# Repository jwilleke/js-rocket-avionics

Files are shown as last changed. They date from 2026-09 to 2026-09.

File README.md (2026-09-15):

# js-rocket-avionics

Carrier PCB and flight firmware for the [js-rocket](https://github.com/jwilleke/js-rocket) electronics sled.

__This is one candidate payload for the rocket, not *the* payload.__ The rocket flies on ballast alone. The interface it has to satisfy — 40.0 mm bore × 150 mm, an M3 × 55 retainer at nose z 15, a ~50 g mass ceiling, an optional camera port — is [`js-rocket/docs/payload-bay.md`](https://github.com/jwilleke/js-rocket/blob/main/docs/payload-bay.md), and that is the only page in that repo this project depends on.

__Flying the rocket, not building it? Read [docs/using-avionics.md](docs/using-avionics.md)__ — what the electronics do, and what to do before, during and after a flight. Everything below is for builders.

Separate from the rocket repo on purpose: `js-rocket` is geometry and documentation with no code, no package manager and no dependencies, and its `CLAUDE.md` says so explicitly. Copper, firmware and __the design record — every decision and why, in [docs/design.md](docs/design.md)__ — live here instead.

__Why it is built this way is in [docs/design.md](docs/design.md).__ __Every part this project needs is in [docs/BOM.md](docs/BOM.md), which is the single source of truth for part numbers and weights__ — plus what each part is, which board it serves, and what was rejected. __What was actually bought is in [docs/shopping-list.md](docs/shopping-list.md)__ — orders, costs, arrival status. The printed sled that carries these boards, and the [PayloadAdapter](https://github.com/jwilleke/js-rocket/blob/main/docs/3d-printed-parts/payload-adapter.md) it loads through, are rocket parts and stay in [js-rocket](https://github.com/jwilleke/js-rocket).

__Status: one two-sided board ([PCB-carrier-design.md](hardware/PCB-carrier/PCB-carrier-design.md)). Every footprint placed and netted, DRC 0 violations.__ The 10 unconnected items DRC reports are the signal nets, which are not routed yet (stage 2d, [#15](https://github.com/jwilleke/js-rocket-avionics/issues/15)). What the board is, both sides with a drawing, is [hardware/PCB-carrier/PCB-carrier.md](hardware/PCB-carrier/PCB-carrier.md).

> __Do not order it.__ It quotes cleanly, which is a toolchain check and nothing more. It is unrouted, and two checks are still owed (PCB-carrier-design.md, *Checks owed before building*).

## What a flight records

__Planned, not yet written.__ The recorder firmware on XIAO-ESP32S3-cam is __not started__ — today a flight would record nothing. The GPS is not recorded at all; its only copy is what the ground receiver hears.

| Data | From | Recorded? | Where it ends up |
|---|---|---|---|
| Acceleration and rotation | [LSM6DSO32](hardware/LSM6DSO32/LSM6DSO32.md), XIAO-ESP32S3-cam | __planned__ — 500 Hz, read from the sensor's FIFO | PSRAM through the flight (~900 KB a minute), __written to microSD in slices as it goes__ |
| Pressure, so altitude | [BMP388](hardware/BMP388-barometer/BMP388-barometer.md), XIAO-ESP32S3-cam | __planned__ — in the same log | the same |
| Video | OV3660 on the [Sense camera board](hardware/Sense-camera-board/Sense-camera-board.md), XIAO-ESP32S3-cam | __planned__ — from launch, with a few seconds before it, until landing is detected; idle on the pad | microSD, as it records |
| Position and GPS altitude | [L76K-GNSS](hardware/L76K-GNSS/L76K-GNSS.md), XIAO-ESP32S3-lora | __no__ — broadcast over LoRa by stock Meshtastic every so often, stored nowhere on the rocket | the ground receiver and the phone on it — [#23](https://github.com/jwilleke/js-rocket-avionics/issues/23), ordered 2026-09-11 |

__Two things that follow:__

- __A reset of XIAO-ESP32S3-cam in flight loses the slice of the sensor log not yet on the card__ — the rest is already written. Whether the shared battery browns it out is [#8](https://github.com/jwilleke/js-rocket-avionics/issues/8)
- __The sensor log has no GPS in it.__ The two XIAOs share power and nothing else, so position and motion are never in one record

Why the log sits in PSRAM rather than going straight to the card: [design.md](docs/design.md#data-path--why-the-log-lives-in-psram).

## The interface to the sled

__One board on the PayloadSled's centre line__, hanging off the web on two standoffs: the tall side (both XIAO stacks) faces 270°, the camera port; the low side (sensors, standoffs) faces 90°, the web. The sled side is [js-rocket#99](https://github.com/jwilleke/js-rocket/issues/99), which moves the web toward 90° and drills it at the standoffs. __Change these and the sled changes.__

| | Value |
|---|---|
| Board | __24.0 × 115.7 mm__, aft end at nose z 25.4, forward end 141.1 |
| Thickness | __1.6 mm__, 4 copper layers — OSH Park's only 4-layer thickness |
| Corner radius | 2.0 mm |
| Standoffs | __2 × Würth WA-SMSI M3, 10 mm__ (9774100360), low side, at board (x, y) __(12.0, 4.0)__ and __(16.5, 110.5)__ — nose z 29.4 and 135.9, neither under a module. M3 plastic screws, __M3 × 10__, from the web's far face |
| XIAO-ESP32S3-cam centre | board y __18.0__ (nose z 43.4), under the camera pad |
| XIAO-ESP32S3-lora centre | board y __68.0__ (nose z 93.4) |

Board x runs across the board, y from the aft end, forward positive, in KiCad's top view (the tall side). Everything above is read out of the generated board by `gen_carrier.py`; the gerbers in `fab/` predate it ([#16](https://github.com/jwilleke/js-rocket-avionics/issues/16)).

__Why 24 mm wide.__ It matches the web. The sensors, 17.8 mm across when lengthwise, sit inside it.

__Why 115.7 mm long.__ The camera fixes the cam XIAO at the aft end, and the tall side then carries the L76K-GNSS, the lora XIAO and the JST end to end. The low side carries the battery as well as the sensors (layout B2, 2026-09-15): LSM6DSO32 aft, the battery behind the L76K and the lora XIAO, the BMP388 forward of it — and the BMP388's M2 legs have to land between the tall side's header rows, which is what fixes where it can go. 90.4 mm until the battery moved onto the board.

__Why 1.6 mm.__ It is the only thickness OSH Park makes a 4-layer board in — "63mil (1.6mm) nominal". The 1.0 mm this page carried until 2026-09-15 was never checked against the fab; the operator caught it on the printed fit mock ("looks too thin"). It is also the better board: the standoffs are now __106.5 mm apart__ (81 before 2026-09-15), and 1.6 mm is __about 4× as stiff__ as 1.0 over that span (stiffness goes as thickness cubed). The low face — the standoffs' face — stays at r 0.5, so the sled does not change; the tall side moves __0.6 mm toward 270°__. What that costs across the bore is in [PCB-carrier-design.md](hardware/PCB-carrier/PCB-carrier-design.md#across-the-bore)

## The XIAO stack

__The expansion board — Sense or Wio-SX1262 — sits above the XIAO__, on the B2B connector on its front face. The XIAO stands on __two standard 7-pin headers__, ~2.50 mm, onto the board. No cutout and no tall stacking headers are needed. Stack heights and the fit across the bore are in [docs/design.md](docs/design.md#headers-and-the-expansion-board-on-top).

## Connections

There is __no schematic file__. Nets are assigned to pads directly in the generator, which is more robust than hand-authoring schematic s-expressions for 9 nets and keeps one generator as the single source of truth. The cost is no ERC and no drawn diagram — so this table *is* the wiring diagram. __Keep it in step with `gen_carrier.py`.__

| Net | From | Also reaches |
|---|---|---|
| `GND` | both XIAOs, pin 13 | In1 plane, every module, JST −, the `GND` wire pads |
| `+3V3` | XIAO-ESP32S3-cam pin 12 __only__ | In2 plane; LSM6DSO32 `VIN`; BMP388 `VIN` __and `CS`__ (I2C mode, [#19](https://github.com/jwilleke/js-rocket-avionics/issues/19)) |
| `+3V3_LORA` | XIAO-ESP32S3-lora pin 12 | the L76K-GNSS's `3V3` only — __kept off the plane__, so the two regulators are never paralleled |
| `SDA` | cam __D4__ (pin 5, GPIO5) | LSM6DSO32, BMP388 |
| `SCL` | cam __D5__ (pin 6, GPIO6) | LSM6DSO32, BMP388 |
| `BUZZER` | cam __D0__ (pin 1, GPIO1) | the buzzer wire pad; the PS1240 sits against the nose wall |
| `GPS_TX` | lora __D6__ (pin 7, GPIO43) | the L76K-GNSS's pad at the D6 position, which is the module's __RX__ |
| `GPS_RX` | lora __D7__ (pin 8, GPIO44) | the L76K-GNSS's pad at the D7 position, which is the module's __TX__ |
| `VBAT` | JST pin 1 | both XIAOs' BAT pigtail pads |

`GPS_TX` and `GPS_RX` are named from the XIAO's side. __Wire the L76K-GNSS by position, never by its silkscreen word__ — [L76K-GNSS.md](hardware/L76K-GNSS/L76K-GNSS.md#pinout--from-seeeds-schematic-not-the-listing).

### The pin map, and an error worth not repeating

The KiCad footprint numbers its pads 1–14 with no signal names, DIP-style — 1 at top-left, down to 7 at bottom-left, 8 at bottom-right, up to 14 at top-right. Seeed's pinout gives the meaning:

```text
pin  1  2  3  4  5  6  7   8  9  10  11   12   13   14
sig  D0 D1 D2 D3 D4 D5 D6  D7 D8 D9  D10  3V3  GND  5V
```

An earlier revision of the generator put GPS on pins 6/7 and I2C on 4/5 — which are __D5/D6 and D3/D4, every one off by one__. Caught by reading the mapping back out of the saved board rather than trusting the script's own output. The generator now names pins (`XIAO_PIN["D6"]`) so the numbers never appear by hand.

__Each 1×7 header numbers its own pads 1–7.__ The second row's pad 1 is XIAO pin 8, at the far end, so `xiao_pin = pad + 7` running back toward the USB-C. This file once said `15 − pad`, which is [#18](https://github.com/jwilleke/js-rocket-avionics/issues/18)'s mirrored row, written down as the rule.

## The GPS is an L76K

The MAX-M10S was rejected on 2026-08-06: __44.2 × 30.5 mm — wider than this 24 mm board — and ~$60__. The chosen part is Seeed's __L76K GNSS for XIAO (109100021)__ — 18 × 21 mm, UART on __D6/D7__. It takes its own footprint on the tall side, between the two XIAOs, and its antenna is a separate part on the sled. Pinout, power and orientation: [L76K-GNSS.md](hardware/L76K-GNSS/L76K-GNSS.md).

The same staleness once reached the barometer: __BMP390 → BMP388__, settled on 2026-08-06 when the 390 went out of stock. Same BMP3xx driver, same 25.5 × 17.8 mm STEMMA QT outline, address 0x77, and its pinout __confirmed off the physical part__.

## Battery — read before assembling

__BAT+/BAT− are underside pads on the XIAO__, not brought out to the castellated edge, so the battery cannot reach a XIAO through the headers. The battery lands on the JST at the board's forward end and reaches each XIAO by a short __soldered pigtail__.

- __Solder the pigtails before the XIAO goes onto its headers.__ The board, not the expansion board, is what covers the pads.
- __On battery power there is no voltage on the 5V pin__ — nothing can be fed from a XIAO's 5V rail.
- Both XIAO chargers sit in parallel on one battery. __Charge through one USB port at a time__, and read [why that is not sufficient on its own](hardware/LiPo-500mAh/LiPo-500mAh.md#two-chargers-on-one-battery).
- __Check JST pin 1 against the battery's red lead before soldering.__ The silkscreen marks `+`; reversing a LiPo into a XIAO destroys it.

## No RF on this board

The L76K and the Wio-SX1262 each carry their own U.FL connector, and both antennas mount on the sled, so __no RF ever crosses the carrier__. It is a purely digital and power board of 9 nets, which is what makes it tractable to generate and verify headlessly.

## Building

Requires KiCad 10. The generator uses KiCad's bundled Python so `pcbnew` matches the CLI exactly.

```bash
KPY=/Applications/KiCad/KiCad.app/Contents/Frameworks/Python.framework/Versions/3.9/bin/python3
CLI=/Applications/KiCad/KiCad.app/Contents/MacOS/kicad-cli

$KPY hardware/scripts/gen_carrier.py
$CLI pcb drc  --format json -o /tmp/drc.json hardware/PCB-carrier/PCB-carrier.kicad_pcb
$CLI pcb export gerbers -o fab/gerbers/ hardware/PCB-carrier/PCB-carrier.kicad_pcb
$CLI pcb export drill   -o fab/gerbers/ hardware/PCB-carrier/PCB-carrier.kicad_pcb
```

__The board is generated, not hand-edited.__ `.kicad_pcb` format shifts between KiCad releases; building it through `pcbnew` means the file is written by the same code that reads it. Edit `hardware/scripts/gen_carrier.py` and re-run — do not edit the board file directly, or the next run overwrites you.

`gen_outline.py` is the superseded 2a-only version, kept for reference.

DRC must report __0 violations__ before anything is ordered.

## Remaining stages

| Stage | State |
|---|---|
| 2a — outline, standoffs, stackup | __done__, one two-sided board |
| 2b — nets + footprints | __done__ — every footprint placed and netted |
| 2b — GND/+3V3 planes | __done__, In1 and In2 filled |
| 2c — placement | __done in the generator__, pending review of the drawing — [#14](https://github.com/jwilleke/js-rocket-avionics/issues/14) |
| 2d — signal routing | not started — [#15](https://github.com/jwilleke/js-rocket-avionics/issues/15) |
| 2e — Gerber + drill for fab | chain proven; needs a finished board |

__Do not order copper before breadboarding.__ A layout error costs ~$43 and two weeks; a wiring error costs minutes.

Fab target is __OSH Park__. The 24 × 70 mm version quoted **$26.00 for 3 copies** — OSH Park's 4-layer price is $10/in² for three — so 24 × 115.7 mm (4.30 in²) should land near __$43__. Re-upload to confirm; three copies — one to fly, two spares.

__OSH Park accepts the `.kicad_pcb` directly__ — confirmed by upload, not assumed. It read the layer count and outline unaided, so `fab/gerbers/` is not in the ordering path and exists only as a check that the export chain works.

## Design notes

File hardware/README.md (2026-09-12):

# Hardware

__One page per part, and the source of truth for the hardware in use.__ What each part is, its interfaces and dimensions, and the traps that are properties of the object.

__These pages are not a history and not a task list.__ They say what is, not what changed or what to do next. Decisions and open work live in [issues](https://github.com/jwilleke/js-rocket-avionics/issues); what happened in a session lives in `private/project_log.md`; the reasoning behind the design lives in [design.md](../docs/design.md).

__These pages also fix the vocabulary.__ A part is called by the name of its page here — [XIAO-ESP32S3-cam](XIAO-ESP32S3-cam/XIAO-ESP32S3-cam.md) and [XIAO-ESP32S3-lora](XIAO-ESP32S3-lora/XIAO-ESP32S3-lora.md), never "board A" and "board B" — and where a page has a plain-English word for the thing, that word is the one to use. __The [LiPo-500mAh](LiPo-500mAh/LiPo-500mAh.md) is the battery.__ It is not "the cell": that is a word from datasheets, it reads as jargon to everyone who has to work on this, and one battery made of one cell gains nothing by the distinction.

## The names, and where they live

__One folder per part. The folder, the page inside it and the part all carry the same name.__ Adopted 2026-09-09. `hardware/BMP388-barometer/BMP388-barometer.md` — not `README.md`, because a folder that already names the part does not need a second word for it. __A part's own photographs live in its folder__, beside its page.

__These are the names. Nothing else is a name for these things:__

| Folder and page | Is |
|---|---|
| `XIAO-ESP32S3-cam` | The MCU module carrying the camera. Never "board B", never "the Sense one" |
| `XIAO-ESP32S3-lora` | The MCU module carrying the radio. Never "board A" |
| `Sense-camera-board` | The expansion board on XIAO-ESP32S3-cam |
| `Wio-SX1262-LoRa` | The LoRa radio |
| `L76K-GNSS` | The GNSS module |
| `LSM6DSO32` | The IMU |
| `BMP388-barometer` | The barometer |
| `PS1240-buzzer` | The buzzer |
| `LiPo-500mAh` | __The battery.__ Never "the cell" |
| `Arming-switch` | The arming switch. __Not the JST__, which is a connector |
| `Stacking-headers` | The 7-pin strips |
| `Antennas` | Both U.FL antennas |
| `microSD` | The card |
| `PCB-carrier` | The carrier board |
| `camera-stack` | XIAO-ESP32S3-cam __with__ its Sense board — the assembly, not either part |
| `GNSS-stack` | __A rejected arrangement, not a thing that exists.__ Kept so it is not proposed again |

__Where a part has no folder here, it is not a part of this payload.__ "XIAO" on its own is not a name: there are two of them and they are not interchangeable.

__Two exceptions to "photographs live with the part".__ [`docs/resources/`](../docs/resources/) keeps the images that belong to __both__ XIAO modules — the front and back pinouts, the module and underside shots — because they document the model rather than either role, and a second copy is a copy that drifts. [`docs/bench-work/`](../docs/bench-work/) keeps what belongs to no part at all: the breadboard drawing, the bench photograph and the measurement grid.

__These pages hold no part numbers and no masses.__ [BOM.md](../docs/BOM.md) owns both and says so: *"anything else that quotes a part number or a mass is wrong — link here instead."* A number in two places is a number that will disagree with itself.

| | Page | Goes with | Photos | What it is |
|---|---|---|---|---|
| MCU | [XIAO-ESP32S3-lora.md](XIAO-ESP32S3-lora/XIAO-ESP32S3-lora.md) | — | grid | The MCU module. __Runs stock Meshtastic__ — identical to the cam copy to look at; [which is which](XIAO-ESP32S3-lora/XIAO-ESP32S3-lora.md#which-xiao-is-this-one) |
| MCU | [XIAO-ESP32S3-cam.md](XIAO-ESP32S3-cam/XIAO-ESP32S3-cam.md) | — | grid + bench | The MCU module. On the bench with both sensors and the buzzer; runs `bringup-cam` |
| Payload | [Sense-camera-board.md](Sense-camera-board/Sense-camera-board.md) | XIAO-ESP32S3-cam | grid ×2 | OV3660 camera and the microSD slot |
| Radio | [Wio-SX1262-LoRa.md](Wio-SX1262-LoRa/Wio-SX1262-LoRa.md) | XIAO-ESP32S3-lora | grid | LoRa. Buy as the matched kit, never separately |
| GNSS | [L76K-GNSS.md](L76K-GNSS/L76K-GNSS.md) | XIAO-ESP32S3-lora | grid | Position. __Flat on the carrier's tall side__, own footprint |
| Sensor | [LSM6DSO32.md](LSM6DSO32/LSM6DSO32.md) | carrier | grid + back | ±32 g IMU with a 9 KB FIFO |
| Sensor | [BMP388-barometer.md](BMP388-barometer/BMP388-barometer.md) | carrier | grid + 2 close | Unported barometer, 0x77 |
| Output | [PS1240-buzzer.md](PS1240-buzzer/PS1240-buzzer.md) | carrier | __none__ | Passive piezo. The only status channel on the pad |
| Power | [LiPo-500mAh.md](LiPo-500mAh/LiPo-500mAh.md) | carrier | __none__ | One battery, both XIAOs |
| Power | [Arming-switch.md](Arming-switch/Arming-switch.md) | battery lead | __n/a__ | In the battery line. __Flight 3 carries none__ |
| Storage | [microSD.md](microSD/microSD.md) | Sense camera board | __none__ | Video only |
| RF | [Antennas.md](Antennas/Antennas.md) | Wio-SX1262, L76K | grid | Both off-board on U.FL. ≥50 mm apart |
| Mechanical | [Stacking-headers.md](Stacking-headers/Stacking-headers.md) | both XIAOs | __none__ | 7-pin strips, ~2.50 mm standoff |
| Mechanical | [PCB-carrier.md](PCB-carrier/PCB-carrier.md) | everything | __n/a__ | The board, and the sled's structural span |
| Assembly | [camera-stack.md](camera-stack/camera-stack.md) | — | end + side | XIAO-ESP32S3-cam with its Sense board, as one object |
| Assembly | [GNSS-stack.md](GNSS-stack/GNSS-stack.md) | — | __none__ | __Rejected.__ Why the L76K is not in a stack |

## Photographs

__Each part's images live in that part's folder__, beside its page; the two shared XIAO images stay in [`docs/resources/`](../docs/resources/). Every one is embedded on the page above. __Shot on the printed measurement grid__ — part flat, square-on, calibration bar in frame. Method and its precision: [module-pinouts.md](../docs/module-pinouts.md#how-these-are-measured--photograph-on-the-grid-not-calipers).

| Image | Part | What it is for |
|---|---|---|
| [`BMP388-front-grid.jpg`](BMP388-barometer/BMP388-front-grid.jpg) | BMP388 | __Dimensional record.__ Header row along the bottom, mounting holes at the top corners |
| [`BMP388-front.jpg`](BMP388-barometer/BMP388-front.jpg) | BMP388 | Close-up. Confirms pin order on the silkscreen |
| [`BMP388-back.jpg`](BMP388-barometer/BMP388-back.jpg) | BMP388 | Close-up. Address jumper, `3 V` marking |
| [`LSM6DSO32-front.jpg`](LSM6DSO32/LSM6DSO32-front.jpg) | LSM6DSO32 | __Dimensional record.__ Both header rows and both mounting holes |
| [`LSM6DSO32-back.jpg`](LSM6DSO32/LSM6DSO32-back.jpg) | LSM6DSO32 | Close-up. `ST LSM6DSO32`, ±32 g, `0x6A` |
| [`L76K-GNSS.jpg`](L76K-GNSS/L76K-GNSS.jpg) | L76K | Module and its ≈25 mm patch antenna, to scale |
| [`Wio-SX1262-LoRa.jpg`](Wio-SX1262-LoRa/Wio-SX1262-LoRa.jpg) | Wio-SX1262 | FCC ID, U.FL, and the 2×5 header currently fitted |
| [`Wio-SX1262-LoRa-antennas.jpg`](Wio-SX1262-LoRa/Wio-SX1262-LoRa-antennas.jpg) | Antennas | Both Seeed strips, to scale |
| [`XIAO-ESP32S3-module.jpg`](../docs/resources/XIAO-ESP32S3-module.jpg) | XIAO ×2 | The MCU board. USB-C, U.FL, B2B, 14 pads |
| [`XIAO-ESP32-S3-bottom.jpg`](../docs/resources/XIAO-ESP32-S3-bottom.jpg) | XIAO ×2 | __The pin labels.__ Underside, where the silkscreen is — the only reading that confirms pad 1 is `D0`. See [module-pinouts.md](../docs/module-pinouts.md#xiao-esp32s3--read-off-the-underside-2026-09-08) |
| [`2026-09-12-XIAO-ESP32S3-cam-bench.jpg`](XIAO-ESP32S3-cam/2026-09-12-XIAO-ESP32S3-cam-bench.jpg) | XIAO-ESP32S3-cam | __Bench, not grid.__ The cam breadboard, sensors and buzzer wired, no Sense board — with the I2C wires on D3/D4, the slip since fixed |
| [`XIAO-ESP32S3-Sense-expansion.jpg`](Sense-camera-board/XIAO-ESP32S3-Sense-expansion.jpg) | Sense | Camera and microSD board |
| [`XIAO-ESP32S3-Sense-stack-end.jpg`](camera-stack/XIAO-ESP32S3-Sense-stack-end.jpg) | camera-stack | __End-on.__ Settled that the expansion board mates to the front face and sits above |
| [`XIAO-ESP32S3-Sense-stack-side.jpg`](camera-stack/XIAO-ESP32S3-Sense-stack-side.jpg) | camera-stack | The same assembly from the side |

## The two stacks

__Name everything by its page.__ There is no "board A", no "board B", and no functional nickname — the two MCU modules are told apart by which expansion board is on them, which is what their filenames say.

| | Mated to it | Firmware |
|---|---|---|
| __XIAO-ESP32S3-lora__ | [Wio-SX1262](Wio-SX1262-LoRa/Wio-SX1262-LoRa.md) radio, [L76K](L76K-GNSS/L76K-GNSS.md) GNSS | __none written__ — stock Meshtastic, pre-flashed |
| __XIAO-ESP32S3-cam__ | [Sense camera board](Sense-camera-board/Sense-camera-board.md) | custom, not started |

__The two XIAO modules are the same part but not interchangeable in practice__ — the lora one arrived with its 7-pin headers soldered on, the cam one did not.

Both ride the one [carrier PCB](PCB-carrier/PCB-carrier.md), on its tall side. The IMU and barometer sit on its low side, not on either expansion board; the buzzer and both antennas are off the board.

## Fasteners

__The carrier hangs off the sled's web on two surface-mount M3 standoffs__ (Würth WA-SMSI, 10 mm), with __M3 plastic screws, M3 × 10__, driven in from the web's far face (operator, 2026-09-11; [PCB-carrier.md](PCB-carrier/PCB-carrier.md)). The length matters: a longer screw passes through the standoff and out of the board's tall side. The old "M2 everywhere" standard (2026-09-05) was for screwing the breakouts down, which is no longer done.

__The sensors are not screwed through the board__, because nothing may stick out of its back: the LSM6DSO32 is soldered by both its rows, and the BMP388's free edge rests on __M2 bolts through its own holes, head down__ on the board. M2 survives only there, and only because those holes measure __Ø2.35__: an M2 passes, an M2.5 does not, and an M3 never could.

__Printed holes are modelled oversize.__ A hole modelled at nominal prints undersize by ~0.3 mm on the P2S, so the sled's M3 holes are drawn for clearance rather than at 3.0 — the same rule as the anchor bore in the rocket repo.

## What is not here

- __KiCad sources__ — [`PCB-carrier/`](PCB-carrier/), beside the page that documents the board
- __Generators__ — `scripts/`, including `gen_carrier.py`
- __Measured pin order and caliper readings__ — [module-pinouts.md](../docs/module-pinouts.md)
- __Why it is built this way__ — [design.md](../docs/design.md)
- __Bench drawings and the measurement grid__ — [`docs/bench-work/`](../docs/bench-work/)

---

Part numbers, vendors and masses live in [BOM.md](../docs/BOM.md), which is the single source of truth for both. Purchase history is in [shopping-list.md](../docs/shopping-list.md); the reasoning is in [design.md](../docs/design.md).

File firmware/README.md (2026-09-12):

# Firmware

__PlatformIO projects. No `.ino` files__ (operator, 2026-09-08).

A sketch carries its build configuration in IDE menu state — which board, whether PSRAM is on, which partition table. None of that is in the file, so a sketch that works on one machine fails on the next and the failure looks like a hardware fault. A `platformio.ini` puts every one of those settings in the repo, next to the code, under version control.

| Project | For | State |
|---|---|---|
| [`bringup-cam/`](bringup-cam/) | [XIAO-ESP32S3-cam](../hardware/XIAO-ESP32S3-cam/XIAO-ESP32S3-cam.md) + [Sense-camera-board](../hardware/Sense-camera-board/Sense-camera-board.md) bench bring-up, [#7](https://github.com/jwilleke/js-rocket-avionics/issues/7) | __run 2026-09-12, all pass__: I2C, IMU, a camera frame, 5 s of video, and a 1 MB PSRAM log flushed and read back. SD over SPI at 20 MHz, CS on GPIO21. Prints its device name, `mj-cam` |
| [`stack-load-test/`](../hardware/camera-stack/stack-load-test/) — __lives with [camera-stack](../hardware/camera-stack/camera-stack.md)__ | the camera stack at flight load: IMU + baro sampled into PSRAM while video records, all at once — design.md Verification item 4 | __run 2026-09-12__: zero dropped IMU samples in 60 s; 4.8% of frames dropped on purpose; worst card stall 1 191 ms |
| [`i2c-find/`](i2c-find/) | when `bringup-cam` finds nothing on the bus: which XIAO pins carry the I2C pull-ups, and on which pair the sensors answer | __run 2026-09-12__ — found the wires on D3/D4 |
| [`soak-power/`](soak-power/) | the shared-battery load test, [#8](https://github.com/jwilleke/js-rocket-avionics/issues/8) — drives capture + SD write bursts and logs every cycle and every reset to the card | __run 2026-09-12__: 67 minutes on the shared battery, 82 925 cycles, no reset on either board. Keeps a reset history in NVS as well as on the card |
| [`gps-check/`](gps-check/) | the [L76K-GNSS](../hardware/L76K-GNSS/L76K-GNSS.md) read directly, no Meshtastic, [#6](https://github.com/jwilleke/js-rocket-avionics/issues/6) — fix, satellites in view, best SNR, time to first fix. __Flashed onto XIAO-ESP32S3-cam__, so a GPS with no position in Meshtastic can be split into "module or antenna" against "Meshtastic not reading D6/D7" | __untested — no hardware has run it__ |

__Unplug XIAO-ESP32S3-lora before any upload.__ PlatformIO uploads to the first port it finds, and with both boards on USB that can be the one that must only ever carry stock Meshtastic.

```sh
cd firmware/bringup-cam
pio run -t upload && pio device monitor
```

__`soak-power` is flashed the same way and then run with the USB unplugged__, because USB-C powers the board and a monitored run measures the bench supply rather than the battery. Its record is `/soak-power.csv` on the card, read after the run.

__None of this is flight firmware.__ Bring-up proves the parts are alive and talking. Apogee, staging and landing detection need the flight profile settled first — see [design.md](../docs/design.md).

__[XIAO-ESP32S3-lora](../hardware/XIAO-ESP32S3-lora/XIAO-ESP32S3-lora.md) has no project here and must not get one.__ It runs stock Meshtastic, pre-flashed, and that is the entire reason there are two modules: a recovery beacon that cannot be broken by our own bugs. Writing firmware for it would throw that away. Updating it to a newer __stock__ release is allowed, on purpose and by a set procedure: [the firmware rule](../hardware/XIAO-ESP32S3-lora/XIAO-ESP32S3-lora.md#firmware--stock-meshtastic-only-updated-on-purpose-frozen-for-flight).

__Board settings come from the board definition, not from this repo__, and both projects pin `platform = espressif32@55.3.35` so that stays true across machines. What is a default, what is deliberately restated, and how to recover a board that will not take an upload: [sense-board-PlatformIO.md](sense-board-PlatformIO.md).

Procedure for running any of this: [bench-bringup.md](../docs/bench-bringup.md).

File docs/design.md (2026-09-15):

# Design record

__Why this payload is built the way it is.__ The decisions and the reasoning behind them, so the *why* survives into the work.

This project is __one candidate payload__ for the js-rocket [payload bay](https://github.com/jwilleke/js-rocket/blob/main/docs/payload-bay.md). The bay's interface — 40.0 mm bore × 150 mm, an M3 × 55 retainer at nose z 15, a ~50 g mass ceiling, an optional 8 mm camera port — is the rocket's business and is not restated here beyond what constrains the design.

Related: [BOM.md](BOM.md) (parts and masses) · [shopping-list.md](shopping-list.md) (what was bought) · [module-pinouts.md](module-pinouts.md) (footprint inputs) · [README.md](../README.md) (the carrier's frozen interface)

## Decisions locked

| Decision | Value | Why |
|---|---|---|
| MCU | __Two__ XIAO ESP32S3, told apart by the expansion board on each — __XIAO-ESP32S3-lora__ and __XIAO-ESP32S3-cam__ | Restores a zero-firmware recovery beacon and isolates it from flight-firmware failure |
| Interconnect | __One two-sided carrier PCB__ on the sled's centre line, hanging off an offset web on two M3 standoffs, 1.6 mm FR4, 4-layer, __24 × 115.7 mm__, the battery on its low face | Both XIAO stacks on one side, facing the camera; the web moved out of the board's way; removable as one unit |
| XIAO-ESP32S3-lora firmware | __Stock Meshtastic__, pre-flashed by Seeed. No code written | The Wio-SX1262 + XIAO ESP32S3 kit is a supported Meshtastic device out of the box |
| XIAO-ESP32S3-cam firmware | Custom — camera, sensors, PSRAM logging, Wi-Fi | Not yet started |
| Camera | __OV3660__ on the Sense expansion board — __confirmed off the ribbon 2026-09-06__, having been recorded as an OV2640 throughout | Estes AstroCam was considered and dropped |
| Barometric static port | __Dropped__ | See below |
| Apogee method | __Inertial primary__; GPS anchor by __offline timestamp merge__, not real time | The cost of putting GPS on the stock-Meshtastic board |
| Flight log storage | __Buffer in PSRAM, and write it to the card in slices as it goes__ (operator, 2026-09-12) | The sampler never writes the card itself — a separate writer task does, so a card stall delays the slice, never a sample |
| Power | __One battery__ to a carrier JST, distributed to each XIAO's __underside BAT pads by soldered pigtail__. __Charge through one USB port at a time__ | BAT is not on the castellated edge, so it cannot come through the headers. Avoids adding a charge IC |
| Arming | __In the battery line__, not on a GPIO — and __flight 3 flies without one__ (2026-09-08). Mechanism and status: [Arming-switch.md](../hardware/Arming-switch/Arming-switch.md) | Physically cuts power; zero pins; cuts both modules at once. Deferred rather than replaced: __nothing else takes the role__ |
| Antennas | __Both off-board on U.FL__ — GPS patch forward-facing, LoRa 82 mm whip up the ogive | A GPS patch needs a 30–40 mm ground plane; a 24 mm board never will be |

## Why two boards, after settling on one

A single board collapsed everything into one custom firmware image: DVP camera, microSD, PSRAM buffer, I2C sensors, SX1262 on non-standard pins, Wi-Fi, OTA. __No stock image does any of that__, which meant:

- first flight gated on firmware being *finished*, not merely working — the beacon __is__ the recovery system;
- a boot-loop at the pad requires removing the M3 × 55, the nose and the sled, with a laptop present, because USB is unreachable assembled and OTA needs firmware that boots;
- stock Meshtastic could not be flashed as a rescue, because the radio would be on custom pins.

Two boards restore the fallback and, as a side effect, dissolve two other problems: XIAO-ESP32S3-cam sheds LoRa (4 pads) and GPS UART (2), so __an I2C GPIO expander is no longer needed__, and XIAO-ESP32S3-cam's SPI carries only the microSD, so __a "no transmit while recording" scheduling rule is unnecessary__ — different MCU, different bus.

Two boards cost __~3 g__ against a single-MCU design, and buy the zero-firmware beacon, failure isolation, the end of pin scarcity, and the end of SPI contention.

## Why the barometric port is dropped

1. __No legal location.__ Ports need a straight section ≥1 caliber clear of any transition. Caliber is 56.7 mm; the longest straight run above the sled is the 56.7 body at __18.6 mm = 0.33 cal__.
2. __Cannot be built.__ Extending that body to a full caliber costs __+38 mm__ against __15.9 mm__ of P2S build headroom — the ogive would shorten and 3:1 fineness breaks.
3. __Unrepeatable.__ Hand-drilled into a part with no generator that takes 2 h 48 m to print.
4. __Drags a pressure bulkhead in with it__ — a new part and a new failure mode.
5. __Decisive: nothing consumes the number.__ No pyro channels; ejection is the motor delay. Apogee is data, not deployment.

A __barometer is still carried, unported and demoted__ to ejection-event timestamp and landing detection. A __contamination bulkhead__ (foam/plate, no sealing duty) still belongs at the sled base to keep black-powder particulate off the boards.

Side benefit: this frees the contested nose wall for the camera lens.

## The carrier PCB

__One two-sided board on the PayloadSled's centre line__, hanging off the web on two M3 standoffs (operator, 2026-09-11). The __tall side__ faces 270°, the camera port, and carries both XIAO stacks, the L76K-GNSS and the JST; the __low side__ faces 90°, the web, and carries the sensors. What the board is, both sides, is [PCB-carrier.md](../hardware/PCB-carrier/PCB-carrier.md); the design record is [PCB-carrier-design.md](../hardware/PCB-carrier/PCB-carrier-design.md). This section is why.

### How it got here

1. __Twin boards first__, one per XIAO. Dropped because each XIAO was thought to need a __cutout__ for an expansion board hanging underneath.
2. __One two-sided board on the sled's centre plane__ replaced it: 24 × 95 mm, lora on one face, cam on the other.
3. __Both premises failed.__ The expansion board sits __above__ the XIAO, so no cutout was ever needed. And the sled's web is a __solid 3 mm plate on that same centre plane__: the camera-port drawing every carrier dimension came from had modelled the board and the web in the same place ([#13](https://github.com/jwilleke/js-rocket-avionics/issues/13)).
4. __One board, the web moved.__ The operator kept one board: the web is offset toward 90°, out of its way, and the board hangs off it on standoffs, removable as a unit. Both tall stacks go on one side, one at each end.

### Headers, and the expansion board on top

__The expansion board — Sense or Wio-SX1262 — mates to the XIAO's __front face__, on the B2B connector beside the U.FL socket, and sits __above__ the XIAO.__ The XIAO sits on __two 7-pin headers__, one down each long edge, onto the carrier.

__An old Population table put the expansion board beneath the XIAO, and it was wrong.__ Settled 2026-09-08 against Seeed's front and back pinouts and an end-on photograph of the assembled stack — breadboard, header pins, XIAO, B2B block, expansion board, camera. See [XIAO-ESP32S3-cam.md](../hardware/XIAO-ESP32S3-cam/XIAO-ESP32S3-cam.md#which-face-carries-what--settled-off-seeeds-two-drawings-and-the-stack-itself).

__The back face stays open__, carrying `BAT+`/`BAT−`. The expansion board never covers them; the __carrier__ does, at 2.50 mm, which is why the pigtail is soldered before the XIAO goes onto its headers.

__Measured on the assembled stacks__ — heights from the bottom of the XIAO's PCB, camera excluded, with the headers' 2.50 mm added: __XIAO-ESP32S3-cam 10.72 mm, XIAO-ESP32S3-lora 11.82 mm__.

__How they fit across the 40 mm bore__, with the board on the centre line and the web offset toward 90°:

```text
tall side, toward 270   cam stack top r 11.8   camera pad floor r 14.09   2.3 mm for the ribbon
                        lora stack top r 12.9   its corners r 15.67        4.3 mm inside the door
low side,  toward 90    sensors top r 8.8       web r 10.5-13.5            1.7 mm clear
```

> __An earlier revision of this section had the expansion board hanging __below__ the XIAO in a ~14 mm header gap, giving a 15 mm stack.__ That is not how the parts assemble. The kit's standard 7-pin headers — ~2.50 mm standoff — are adequate, and no tall stacking headers are needed.

The camera hangs off the expansion board __on a flexible ribbon__, so its position is not fixed by the stack.

### Population — one board, two sides

| Side | Faces | Carries |
|---|---|---|
| __Tall__ | 270°, the camera port | XIAO-ESP32S3-cam + Sense camera board (aft, under the camera); L76K-GNSS; XIAO-ESP32S3-lora + Wio-SX1262 (forward); the battery JST |
| __Low__ | 90°, the web | LSM6DSO32 and BMP388, lengthwise; two M3 standoffs |

__The buzzer and both antennas are not on the board.__ The PS1240 sits against the nose wall on two wire pads; the antennas are on the sled ([Antennas.md](../hardware/Antennas/Antennas.md)). Net list: __9 nets__ — +3V3, +3V3_LORA, GND, VBAT, SDA, SCL, BUZZER, GPS_TX, GPS_RX. The wiring table is in the [README](../README.md).

### The GPS is an L76K, not a MAX-M10S

The MAX-M10S was rejected on 2026-08-06: **44.2 × 30.5 mm, wider than the 24 mm carrier, and ~$60**. Seeed's **L76K GNSS for XIAO (109100021)** is 18 × 21 mm, $11.99, active antenna included, and talks UART on __D6/D7__ — already the carrier's netlist.

__It plugs onto the XIAO's own 14 pads rather than presenting a header to the carrier__, so it takes the carrier as a footprint of its own, __on the tall side between the two XIAOs__ (operator, 2026-09-09; 2026-09-11). __Flat on the carrier deleted the stack-height risk__ rather than answering it: whether the L76K cleared the Wio-SX1262 on the B2B was never tested, and a four-high column cantilevered off header pins under boost was the alternative. Component side up it shows a XIAO's __back__ pattern, so its footprint takes the mirrored mapping — see [L76K-GNSS.md](../hardware/L76K-GNSS/L76K-GNSS.md#pinout--from-seeeds-schematic-not-the-listing).

### Power, and the pigtail constraint

__BAT+/BAT− are underside pads on the XIAO__ (footprint pads 16/17, 2.3 × 1.3 mm at x = −4.5), not brought out to the castellated edge — so the battery __cannot__ reach a XIAO through the headers.

- The battery lands on a __JST-PH at the board's forward end__; short __soldered pigtails__ run to each XIAO's BAT pads.
- __Solder those pigtails before the XIAO goes onto its headers.__ The carrier, not the expansion board, is what covers the pads.
- __On battery power there is no voltage on the 5V pin__, so nothing can be fed from a XIAO's 5V rail.
- Both XIAO chargers sit in parallel on one battery. __Charge through one USB port at a time__ — and [one port at a time is not sufficient on its own](../hardware/LiPo-500mAh/LiPo-500mAh.md#two-chargers-on-one-battery).

### Arming

__Flight 3 carries no arming switch__ (operator, 2026-09-08) — see [Arming-switch.md](../hardware/Arming-switch/Arming-switch.md). The part is deferred, not replaced, and __nothing else is promoted into the role__: power is made and broken at the battery's JST, which is a connector and stays one.

__The architecture below is what this document owns, and it has survived every revision of the mechanism__ — it is what any later flight's switch has to satisfy. The switch sits __in series in the battery line__, between the battery and the carrier's JST. It physically cuts power rather than setting a firmware state a boot-loop could defeat, it costs __zero GPIO__, and it __cuts both modules at once__ — arming is all-or-nothing, including the beacon.

__Everything else about it belongs to [Arming-switch.md](../hardware/Arming-switch/Arming-switch.md)__ — which mechanism, what is still open, and why the reed switch, the magnet-polarity question and the MOSFET that used to live in this section are all gone. The short of it: this payload has no pyro, so an "armed" rocket here is one that is recording video, and the switch buys __turnaround, not safety__.

### Build rules

- __4-layer, solid ground plane.__ A few dollars more at this size; fixes return paths and coupling from the camera's DVP flex.
- __1.6 mm FR4__ — OSH Park's only 4-layer thickness ([why](../README.md#the-interface-to-the-sled)). The board hangs off the web on two standoffs 106.5 mm apart; the web is the structure.
- __Module footprints, not bare chips.__ A bare LSM6DSO32 is an LGA-14 at 2.5 × 3 mm and is not hand-solderable. Soldering breakouts down still gives one rigid assembly — apart from the battery pigtails and link, which are unavoidable.
- __Low side first.__ The sensors stand ~1 mm proud on their pins and are soldered before the tall side's modules — [PCB-carrier.md](../hardware/PCB-carrier/PCB-carrier.md#build-rules).
- __Shock.__ Solder the headers — no loose sockets. The battery is tie-wrapped to the sled, never hung off the JST. Conformal coat after bench testing.
- __Mark polarity__ at the JST and the `VBAT` pads — reversing a LiPo into a XIAO destroys it.

## Data path — why the log lives in PSRAM

__The camera is not on SPI.__ The OV3660 uses a __DVP parallel bus__ (14 GPIO) plus I2C/SCCB for control, with frames landing in PSRAM by DMA. What touches SPI is *writing those frames to the microSD*.

__SD latency is unbounded.__ Cards run wear-levelling and garbage collection at will; a normally-2 ms write can take __100–250 ms__, spec-legally — and __the card in hand stalled up to 1 191 ms__ on the bench, 2026-09-12 ([microSD.md](../hardware/microSD/microSD.md#on-the-bench)).

__Internal flash is worse.__ Writing ESP32 internal flash __disables the instruction cache__. A 4 KB sector erase takes ~20–40 ms, during which code executing *from* flash stalls, including ISRs not marked `IRAM_ATTR`. At 500 Hz the sample period is 2 ms, so one erase silently drops __10–20 samples__ — during boost, where the data matters most.

__So: the sampler writes only to PSRAM.__

```text
500 Hz x ~30 B x 60 s  =  900 KB
ESP32-S3R8 PSRAM       =  8 MB
```

The whole flight fits roughly nine times over.

__And the log goes to the card in slices as it is recorded__ (operator, 2026-09-12, [#24](https://github.com/jwilleke/js-rocket-avionics/issues/24)). The sampler never touches the card: a separate writer task, the one that writes the video, copies each new slice from PSRAM to the card, and the PSRAM copy stays whole until landing. A card stall delays a slice and costs no sample — measured: zero dropped at 833 Hz accel + gyro while the card stalled up to 1.2 s ([camera-stack.md](../hardware/camera-stack/camera-stack.md#at-flight-load--stack-load-test)). What slicing buys is a reset: it now costs only the slice not yet written, not the flight. This replaces "zero SD writes in flight, flush on landing", which assumed one thread doing everything.

__Video runs from launch until landing is detected__, then stops (operator, 2026-09-12 and 2026-09-13, [#24](https://github.com/jwilleke/js-rocket-avionics/issues/24)). One battery feeds the beacon too, and the camera and card are its largest load.

- __Idle on the pad, not recording__ (2026-09-13). Plugging the battery in is "on" and the pad wait can be long; at full load the battery lasts 103 minutes ([#8](https://github.com/jwilleke/js-rocket-avionics/issues/8)), and most of that went to recording a rocket sitting still. __Launch detection starts the card writes__
- __A few seconds kept from before launch__ — a ring of recent frames in PSRAM, flushed when launch is detected, so the ignition is on the video. That needs the camera running on the pad, which costs part of the saving; __the pad draw with and without it is to be measured__ (USB meter) before the firmware settles it. Camera off until launch saves more but loses the first ~½–1 s of boost while it starts
- __After landing, recording stops__, and what is left of the battery keeps the beacon talking

## Sensor rationale

- __17.6 g peak on a D12.__ 32.90 N peak thrust / 0.190 kg liftoff mass. __±16 g phone-grade IMUs clip during boost__, and a clipped boost integral destroys the velocity estimate for the whole flight. This is why TeleMega carries an ADXL375, and why __LSM6DSO32 (±32 g)__ was chosen. Cost: less resolution in coast.
- __The gyro is not the apogee sensor.__ The accelerometer is. The gyro exists so body-frame acceleration can be rotated into the earth frame and gravity subtracted off the correct axis as the rocket tips over.
- __Use the IMU's FIFO — do not poll at 500 Hz.__ The LSM6DSO32 carries a 9 KB FIFO. Batch-reading cuts ISR load, relieves the PSRAM path, and means a brief stall queues samples in the sensor instead of losing them. __Treat a FIFO as a hard requirement on any substitute.__
- __The buzzer does three jobs.__ (1) Last-20-metre locator — GPS lands you in a 3–10 m circle and a white PLA rocket vanishes in tall grass at 2 m. (2) __The only status channel on the pad__ — with the nose assembled, USB is unreachable, Wi-Fi is off, and the GPIO21 LED is sealed inside, so beep patterns are the only way the rocket reports booted / armed / sensors alive. (3) Beeping apogee in digits after landing, needing no phone.
- __The buzzer is *passive*, PWM-driven from D0.__ An earlier revision specified an active self-oscillating part, because the buzzer then hung off an I2C GPIO expander where a ~3 kHz tone meant 6000 bus transactions a second. Two boards freed the pins, the expander went, and a real GPIO can PWM a passive element directly — giving __multiple tones__ rather than one, which is what makes beep patterns readable as distinct codes.
- __The buzzer is not radio redundancy__ — it shares XIAO-ESP32S3-cam's MCU. Only a self-powered beeper with its own battery (~5 g, zero pins) is immune to firmware and MCU failure. Not adopted; revisit if recovery confidence matters more than grams.
- __Sound must escape a sealed PLA cone.__ A piezo in a closed cavity loses 20–30 dB. Mount the disc __against the nose wall__ so the shell acts as a soundboard; the camera port is a free acoustic leak, and the bay is open at its base.
- __The barometer is interchangeable.__ With the static port dropped it is not the altimeter. __BMP388__ shares the BMP3xx driver so it is a drop-in for the out-of-stock BMP390, and a generic BMP280 would serve.

### IMU substitutes — the ±16 g trap

Anything with a ±16 g full scale __clips__ against the 17.6 g boost peak. That rules out almost every cheap module on the market — __MPU6050, LSM6DS3, ICM-20948, ICM-42688-P, ADXL345 are all ±16 g and all unusable here__, however attractive the price.

| Part | Range | Gyro | Note |
|---|---|---|---|
| __LSM6DSO32__ | ±32 g | yes | The chosen part. Adafruit 4692, or a clone — same STEMMA QT layout as the BMP388 |
| __BMI088__ | __±24 g__ | yes | Bosch drone/robotics part, widely stocked, ~$12. 36% margin over 17.6 g |
| __MPU6050 + ADXL375__ | ±16 g + ±200 g | yes | Two chips: one for coast and attitude, one for boost |
| __MPU6050 + H3LIS331DL__ | ±16 g + ±400 g | yes | Same split, more headroom |

The two-chip split is where this design began, before it was consolidated to a single LSM6DSO32 to save a gram. __Reverting costs +1 g and one I2C address — no extra pins.__ A cheap fallback rather than a compromise.

__Integrated 10DOF modules were evaluated and rejected.__ The DFRobot Gravity 10DOF (BMI323 + BMM350 + BMP581, $19.90) is representative: its BMI323 maxes at ±16 g. It is also 32 × 27 mm — wider than the carrier — uses a PH2.0 flying lead, and carries a magnetometer this design deliberately excludes.

## The camera, and the port it needs

> __The part is an OV3660, not an OV2640__ (confirmed 2026-09-06). The analysis below was written for a 2640 and __survives almost intact__: the OV3660's active area is 2048 × 1536 at 1.75 µm = 3.584 × 2.688 mm, a __4.480 mm__ diagonal against the 2640's 4.482 — two microns apart, the same optical format. __What would move the cone is a different focal length__, which a 3 MP module may well carry: at f 4.0 the cone is 58.5°, at f 3.6 it is 63.8°, at f 3.0 it is 73.5°.
>
> __A wider cone makes the port harder.__ At 50° the full cone already needs Ø14.2 mm outside a 15.0 mm collar; at 70° it needs Ø21.3. It was unbuildable from a board-mounted lens and it gets worse. __The standoff fix holds across the whole range__ — with the lens at r 19 the port is Ø4.9 at 50° and Ø7.3 at 70° — which is why bringing the lens to the wall was the right answer rather than a bigger hole.
>
> __Measure the cone rather than looking the lens up.__ Photograph a ruler at a known distance and compute the captured angle. That settles it for the real lens, and this project has already had one argument with a datasheet over this exact number.

__The OV2640's real FOV is ~50°, not the 65–68° commonly quoted.__ Active area diagonal is √(3.590² + 2.684²) = __4.482 mm__; with the stock __f = 4.8 mm__ lens that gives `2·atan(4.482/9.6)` = __50.1° diagonal__ (HFOV 41°, VFOV 31°). The sensor's __25° chief ray angle__ independently confirms it — a 25° half-angle *is* a 50° full cone. The 65–68° figure is inconsistent with both and should be disregarded.

Vignetting is governed by `FOV_cleared = 2·atan(D / (2·(L+S)))`, where L is wall thickness and __S is lens standoff behind the inner wall face__. Standoff, not wall thickness alone, is the constraint:

| Hole D | Standoff budget @ 50° | @ 68° (pessimistic) |
|---|---|---|
| 6 mm | 2.23 mm | 0.25 mm |
| __8 mm__ | __4.38 mm__ | __1.73 mm__ |
| 10 mm | 6.52 mm | 3.21 mm |

__8 mm it is__, and the assembly constraint that follows: keep the lens front element __within ~4.4 mm of the bore's inner face__. Where that hole may be drilled, and the rules for drilling it, are the rocket's business — [payload-bay.md](https://github.com/jwilleke/js-rocket/blob/main/docs/payload-bay.md#the-camera-port).

- __Do not fit the wide-angle lens.__ The 120–160° M7 option cannot match the 25° CRA, producing severe corner vignetting and colour crosstalk, and it would need a far larger hole in a load-bearing collar.
- __Focus is adjustable__ via the M5/M6 lens thread. Hyperfocal at f/2.8 with a ~4.4 µm circle of confusion is ~1.9 m, so everything past ~1 m is sharp.
- __Do not extend the camera flex__ — the DVP bus runs a ~20 MHz XCLK. XIAO-ESP32S3-cam's position on the carrier is what puts the XIAO at nose z 30..45 instead.

## PCB staging

Fab-ready Gerbers are the *output* of a routed board, not something authored directly.

| Stage | Deliverable | State |
|---|---|---|
| 2a | Board outline, mounting holes, stackup | __done__, DRC clean |
| 2b | Nets and footprints | __partial__ — XIAOs placed and netted, pin mapping now asserted on every generate ([#18](https://github.com/jwilleke/js-rocket-avionics/issues/18), closed `c2468eb`); sensors, buzzer, JST deferred |
| 2c | Placement — module positions, keepouts, ≥50 mm antenna separation | blocked on confirming real module pinouts |
| 2d | Routing — 4-layer. Autorouting is wrong here; needs interactive KiCad | not started |
| 2e | Gerber RS-274X + Excellon drill export | chain proven; needs a finished board |

__The PCB outline and mounting-hole pattern had to be frozen before the sled generator was written__, since the sled's rail bosses derive from them.

__Do not order copper before breadboarding.__ A layout error costs ~$33 and two weeks; a wiring error costs minutes.

### Supplier: OSH Park

| Supplier | Fit for this board |
|---|---|
| __OSH Park__ | Quoted __$26.00 for 3 copies__ of the 24 × 70 mm 4-layer board, ENIG standard, __free US shipping__, no customs. Three copies is right: two populated plus a spare. __Recommended__ |
| JLCPCB | Cheaper per unit but __minimum 5__, and shipping (~$20) erases the saving at this size. Right choice if a PCBA service is ever wanted |
| PCBWay | More flexible quoting, generally above JLCPCB's economy tier for simple SMT |

OSH Park wins because we already chose __hand-soldered module footprints__, so assembly service — JLCPCB's real advantage — buys nothing. ENIG also suits the U.FL connectors better than HASL. Trade-off: ~2 week lead versus JLCPCB express.

__Confirmed by upload, not estimated.__ OSH Park accepted the generated `.kicad_pcb` __directly__, detecting 4 layers and the outline unaided — so the Gerber export is not in the ordering path at all. The 95 mm board is 3.53 in² and should land near __$33__; re-confirm at order time.

## Firmware

__Board A needs none__ — the Seeed kit arrives pre-flashed with Meshtastic, and that is the entire premise of the two-board split.

__Board B's flight firmware does not exist yet.__ Camera, sensors, PSRAM buffering, landing detection and the post-landing flush all live there, and nothing has been written.

## Flight sequencing

> __Superseded — operator, 2026-09-13: the avionics fly all or nothing.__ The first avionics flight, [js-rocket flight 3](https://github.com/jwilleke/js-rocket/issues/63), carries the beacon, the recorder and the camera together, or it flies on ballast alone. No beacon-only flight. The staging below is kept as the reasoning it replaced: its job — prove each part before trusting the next — was done on the bench instead ([#4](https://github.com/jwilleke/js-rocket-avionics/issues/4)): the beacon's GPS and Meshtastic ([#6](https://github.com/jwilleke/js-rocket-avionics/issues/6)), the recorder and video, and all of it together on one battery with zero dropped samples ([#7](https://github.com/jwilleke/js-rocket-avionics/issues/7), [#8](https://github.com/jwilleke/js-rocket-avionics/issues/8)). What the bench cannot prove — range from altitude, GPS through PLA in flight — rides on the one flight. So the recorder firmware ([#24](https://github.com/jwilleke/js-rocket-avionics/issues/24)) gates flight 3.

Do not fly all the variables at once.

```text
flight 1   XIAO-ESP32S3-lora only, stock Meshtastic, no camera
           validates: airframe, recovery, GPS lock through PLA, LoRa range from altitude
flight 2   + XIAO-ESP32S3-cam flight recorder (sensors, PSRAM log)
flight 3   + video
```

Each flight adds one thing, and the recovery beacon is proven before anything expensive rides on it. __This is only possible because XIAO-ESP32S3-lora needs no firmware.__

## Verification

1. __Bench prototype before layout.__ Breadboard both populations. Prove XIAO-ESP32S3-lora enumerates as a Meshtastic device untouched, and that XIAO-ESP32S3-cam boots with camera, SD and I2C sensors live, with the strapping pins (GPIO3, 43, 44) behaving.
2. __Confirm the silicon matches the label__ before designing footprints round it — see [module-pinouts.md](module-pinouts.md).
3. __PCB bring-up__ — power, then XIAO-ESP32S3-lora: GPS UART and LoRa; then XIAO-ESP32S3-cam: I2C enumeration and camera. __Measure GPS lock time with the LoRa transmitting__, since desense cannot be reasoned about from a schematic.
4. __Sample-rate integrity under load__ — run XIAO-ESP32S3-cam's 500 Hz sampler with the camera recording to SD and confirm __zero dropped samples__ by checking timestamp deltas, not by trusting the loop. __Done on the bench, 2026-09-12: zero dropped__ at 833 Hz accel + gyro for 60 s while recording, judged by the FIFO's own overrun flag — [camera-stack.md](../hardware/camera-stack/camera-stack.md#at-flight-load--stack-load-test). Repeat on the carrier and on the battery ([#8](https://github.com/jwilleke/js-rocket-avionics/issues/8)).
5. __Shared-battery behaviour__ — confirm the camera's inrush on XIAO-ESP32S3-cam does not brown out XIAO-ESP32S3-lora, and that charging through one USB port with both BAT pads connected behaves.
6. __Buzzer audibility, assembled__ — beep inside a closed Nosecone and listen from 20 m. A sealed cavity costs 20–30 dB; couple the disc harder to the shell before considering a dedicated sound hole.
7. __Mass__ — weigh the loaded sled and hand the real number to the rocket's stability re-run, [#9](https://github.com/jwilleke/js-rocket/issues/9). __Do not fly on the estimate.__

## Risks

- __One board carries both MCUs.__ A layout bug takes the beacon and the recorder together — the cost of a single carrier. Firmware and MCU failures are still isolated; only the copper is shared.
- __No real-time GPS anchor for the inertial log.__ GPS sits on the stock-Meshtastic board, which broadcasts position at a low rate and will not set the `airborne <4g` dynamic model, so lock may drop under boost. Altitude integration is anchored by an __offline timestamp merge__, which is weaker. Cross-linking a UART would fix it and would stop XIAO-ESP32S3-lora being stock, defeating the purpose.
- __A reset of XIAO-ESP32S3-cam loses the slice not yet on the card__ — no longer the whole flight, now the log is written in slices. Two bench findings make resets worth designing out: a task that never yields trips the watchdog, and a reset mid-write can leave the card unmountable until power-cycled ([camera-stack.md](../hardware/camera-stack/camera-stack.md#at-flight-load--stack-load-test)).
- __The PCB is on the critical path.__ Sled geometry derives from its outline and mounting holes, so a layout revision reprints the sled. Freeze the outline early; breadboard before committing to copper.
- __GPS desense from the LoRa transmitter__ cannot be reasoned away on paper. ≥50 mm antenna separation and both antennas on U.FL are the mitigations; verification step 3 is the proof.
- __Shared battery couples the boards__ — and on the bench it did not matter: 67 minutes at full camera load, down to ~3.5 V, reset neither board ([#8](https://github.com/jwilleke/js-rocket-avionics/issues/8), [LiPo-500mAh.md](../hardware/LiPo-500mAh/LiPo-500mAh.md#the-known-risk-observed-no-brownout-at-bench-load)). Repeat on the carrier. The coupling that does bite is charging: the beacon out-draws the charger, so the battery is charged off the carrier.
- __A welded arming contact leaves the camera running.__ It was recorded here as "an armed rocket that cannot be safed", which is a pyro rocket's hazard and not this one's — the correction and the live constraint are in [Arming-switch.md](../hardware/Arming-switch/Arming-switch.md).
- __Estimated masses were unreliable in both directions.__ Nine parts weighed 2026-08-17: the __L76K came in +184%__ and is now the heaviest object in the nose, while the Sense and the radio came in light. Net __+4.1 g__, putting the nose over its ~50 g target — see [BOM.md](BOM.md), which owns every weight.
- __The rocket's stability re-run ([#9](https://github.com/jwilleke/js-rocket/issues/9)) is P0 and blocking.__ This payload can be built and bench-tested now, but __it cannot be flown__ until that clears.

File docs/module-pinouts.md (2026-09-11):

# Module pinouts, measured off the parts

__Footprints cannot be drawn until these are read off the physical parts.__ Vendor listings copy Adafruit's product text verbatim, and this project has already caught two places where the board in hand disagreed with the datasheet it was sold under. A wrong pin order scraps a board rather than costing a re-solder.

__Both sensor boards are confirmed from the parts__ — the BMP388 by caliper, the LSM6DSO32 by pin order and markings off photographs and by every dimension a footprint needs ([#5](https://github.com/jwilleke/js-rocket-avionics/issues/5), closed 2026-09-06). __Nothing else is.__

Moved here from the rocket repo's `electronics-plan.md` — this is footprint input for the carrier PCB, so it belongs with the copper. What each part *is* and why it was chosen stays in [BOM.md](BOM.md); the design record stays in [electronics-plan.md](https://github.com/jwilleke/js-rocket/blob/main/docs/planing/electronics-plan.md).

## How these are measured — photograph on the grid, not calipers

__Adopted 2026-09-06, operator.__ These parts are 17–25 mm and their features sit on a 2.54 mm pitch; __reading 0.1 mm or better off them with calipers is not realistic__, and two attempts at it produced numbers that did not close (a header pair 0.49 mm over the board width, and hole spacing with two routes 0.16 mm apart).

__The method is: lay the part flat on the printed grid, shoot square-on from directly above, keep the calibration bar in frame, and read the dimensions off the image.__ The grid is [`pcb_measurement_grid.pdf`](bench-work/pcb_measurement_grid.pdf); the bar reads `CALIBRATION BAR 100.0 mm`, so the image's own scale is recoverable from the photograph regardless of camera distance.

Why it is better here:

- __It measures to the feature, not to whatever the jaws could reach.__ Most of the readings wanted are edge-to-hole-__centre__, which a caliper cannot do directly and a grid can
- __It is auditable.__ The photograph is committed, so a disputed number can be re-read years later without the part
- __It reads every dimension at once__, rather than one careful reading at a time
- __Its error is honest__ — perspective, and how squarely the shot was taken. Keep the camera above the part, not off to one side

__Realistic precision is ±0.2–0.3 mm__ on a square-on shot — __but only when the image is actually measured__, in an editor or a script that calibrates off the bar and reads pixel coordinates. It is worse than a caliper's theoretical resolution and __better than a caliper's actual result on parts this size__.

> __Eyeballing a photograph is not the same thing and does not get there.__ Reading these images by eye lands at roughly __±1 mm__, which is fine for confirming a pin count, a marking or a rough outline, and __not__ fine for a footprint. Two eyeball reads of the same LSM6DSO32 grid shot gave 24.3 and 24.7 mm against a board known to be 25.5. Where a number is going into copper, measure the image; do not squint at it.

## BMP388 — confirmed from the part

Eight pins, 0.1 in pitch, single row along one long edge, labels alternating above and below:

| Pin | 1 | 2 | 3 | 4 | 5 | 6 | 7 | 8 |
|---|---|---|---|---|---|---|---|---|
| | __VIN__ | 3Vo | __GND__ | __SCL__ | SDO | __SDA__ | CS | INT |

Identical to Adafruit 3966, which labels 4 and 6 as SCK/SDI for SPI — same pins. So it is a true layout clone and the STEMMA QT dimensions (25.5 × 17.8 mm, two mounting holes) hold.

__We use four: 1, 3, 4, 6__ — VIN, GND, SCL, SDA.

__The seller's wiring diagram is SPI, and following it will waste a bench session.__ It wires SCL/SDO/SDA/CS to Arduino 13/12/11/10, which are SCK/MISO/MOSI/SS — the hardware SPI pins. On BMP3xx the pins are dual-purpose: in SPI mode SCL is the clock, SDO is MISO and SDA is MOSI. We use I2C, which needs only the four above.

Two I2C gotchas, both worth knowing *before* bring-up:

- __CS must be HIGH to select I2C.__ CS low puts a BMP3xx into SPI mode. Adafruit's layout pulls it up so I2C is the default and this is a layout clone — but __if the sensor does not enumerate at 0x77, check CS first__. It is the most likely cause.
- __SDO selects the address, it is not data.__ High = 0x77 (default, jumper open), low = 0x76. Leave it alone unless a second barometer is ever added.

__Power to VIN, never to 3Vo.__ `3Vo` is the on-board regulator's *output*; back-feeding it kills the LDO.

__The `3-5VDC` figure did not survive the part arriving.__ This section previously stated the back silkscreen read `Vcc/Logic: 3-5VDC`, which is Adafruit's wording and is what the listing copies. The board in hand is __marked 3 V__. Since the design runs +3V3 into VIN, nothing in it changes — but __5 V is no longer a documented fallback__, and the back silkscreen should be read cleanly before anyone relies on one. It is a good illustration of the rule at the top of this page: the listing describes Adafruit's board, not necessarily this one.

Back silkscreen also confirms __`addr default 0x77`__ with a solder jumper for 0x76, and SPI/I2C selectable.

Header ships __loose and un-soldered__, confirmed on the part — which keeps the mounting orientation open.

## BMP388 — measured 2026-08-08

Calipers and scale, on the board in hand. Photos: [front](../hardware/BMP388-barometer/BMP388-front.jpg), [back](../hardware/BMP388-barometer/BMP388-back.jpg).

| | Measured | Was assumed | |
|---|---|---|---|
| Mass | __1.8 g__ — [BOM.md](BOM.md) owns this figure | 1.0 g (old estimate) | __+80%__ |
| Thickness over Qwiic connectors | __4.79 mm__ | 4.4 mm (Adafruit) | +0.4 |
| Mounting-hole diameter | __Ø2.35 mm__ | 2.5 mm (Adafruit) | __undersize__ |
| Mounting-hole spacing | __20.58 mm__ | — | now known |
| Qwiic cables supplied | 2 × __110 mm__ | "two included" | — |

The front photo confirms the recorded pin order on the physical silkscreen — __VIN, 3Vo, GND, SCL, SDO, SDA, CS, INT__, labels alternating above and below the row — with the two Qwiic connectors on the short edges and both mounting holes on the long edge opposite the header. The layout-clone assumption holds.

__The mounting screw is M2, not M2.5.__ Ø2.35 mm passes an M2 (2.0 mm major) with 0.35 mm of total clearance; an M2.5 does not fit at all. Adafruit's own breakouts use 2.5 mm holes, so anyone sizing this off the datasheet rather than the part will pick a screw that will not go in.

__The sled's bosses must be modelled oversize.__ Same rule as the anchor bore in the rocket repo's [sections.md](https://github.com/jwilleke/js-rocket/blob/main/docs/sections.md) — a hole modelled at nominal prints undersize by ~0.3 mm on that printer. Model for M2 clearance accordingly, and do not copy the 2.35 mm figure straight into CAD.

__20.58 mm of spacing on a 25.5 mm edge__ puts the holes __2.46 mm in from each end__, which is the standard STEMMA QT placement and consistent with the clone claim. __Outline measured 2026-09-06: 25.5 × 17.8 mm__, matching Adafruit's published figures — the one dimension of theirs that survived contact with the part.

## LSM6DSO32 — read off photographs 2026-09-05, not off calipers

Photos: [front](../hardware/LSM6DSO32/LSM6DSO32-front.jpg), [back](../hardware/LSM6DSO32/LSM6DSO32-back.jpg).

__It does not share the BMP388's form factor, which this page assumed it would.__ Two header rows rather than one, and both mounting holes on the same edge as one of them:

| | BMP388 | LSM6DSO32 |
|---|---|---|
| Header rows | __one__, 8 pins | __two__ — 9-pin `Primary I2C/SPI`, 5-pin `Aux. I2C/SPI` |
| Mounting holes | long edge __opposite__ the header | flanking the __Aux__ row, on that edge |

__The flat-mounting conclusion survives, without screws__ (operator, 2026-09-11). Both rows soldered, Primary on one edge and Aux on the other, give two-point restraint across the board, and the part is too light to need more.

__Primary row, 9 pins:__ `VIN 3Vo GND SCL SDA DO CS I1 I2`, labels alternating above and below.

__Aux row, 5 pins:__ `SCX SDX CS DO GND`. Confirm the ordering against the part; a photograph is not a reading.

__Aux row position — measured off the photograph 2026-09-11, not eyeballed.__ It now matters: the row is soldered for support, so its pins must land in real holes. Method: ImageMagick connected components on the full-resolution `LSM6DSO32-front.jpg`, thresholding the gold pad rings and taking all 14 ring centroids, then using __the pin pitch itself as the ruler__ (2.54 mm, exact), so the result does not depend on the camera's scale.

| | Pixels | Result |
|---|---|---|
| Primary-row pitch, pins 1→9 | 198.05 per pitch | 77.97 px/mm |
| Aux pads against Primary pins 3–7 | within 4 px in x | __centred over pins 3–7__ |
| Row gap, three matched pairs | 993.8 mean | __5.02 pitches = 12.75 mm__ |

__So the Aux row is five pitches, 12.70 mm, from the Primary row__ — the standard Adafruit 0.1 in layout, in line with the mounting holes. The Y-offset table below implies 12.11, which would be 4.77 pitches, ~50 px away from what the image shows, so one of its two readings is off by ~0.6 mm. The footprint is drawn on 12.70. Seating the part in a breadboard by both rows is a free cross-check.

Back silkscreen: __`ST LSM6DSO32`__, `6-DoF Accel+Gyro IMU`, __`Accel ±4/8/16/32 g`__, `Gyro ±125~2000 dps`, __`I2C Addr 0x6A`__ with an `AD0` jumper, `I2C VLogic/Vcc: 3-5VDC`, STEMMA QT both short edges, board revision __B__.

Three things that follow:

- __The silicon matches the label__ — the check at the foot of this page passes on this part
- __±32 g is confirmed on the board itself__, not on a listing
- __0x6A does not clash with the BMP388's 0x77__, now confirmed from the part rather than from a datasheet

__`3-5VDC` appears on this board's back and is presumably true here__, unlike the BMP388, where the identical wording came off Adafruit's copy and the part in hand was marked 3 V. The design runs +3V3 either way.

### Measured 2026-09-05

| | Reading | Confidence |
|---|---|---|
| Mounting-hole spacing | __20.58 mm__ | *"appears to be"* — provisional |
| Thickness over Qwiic connectors | __4.80 mm__ | *"about the same"* as the BMP388's 4.79 |
| Header pitch | __2.54 mm__ | confirmed on the BMP388 and the XIAO |
| Board outline | __25.5 × 17.8 mm__ | measured 2026-09-06, __same as the BMP388__ |

__The two sensor boards are the same outline, the same hole pattern and the same thickness.__ 25.5 × 17.8, holes at 20.58 mm centres __2.46 mm in from each end__, 4.79/4.80 thick. For the carrier that means __one footprint outline and one hole pattern, placed twice and rotated__ — not two footprints.

__Both sensors take the same mounting pattern.__ 20.58 mm centres on the LSM6DSO32 against 20.58 mm on the BMP388, and 4.80 mm thick against 4.79 — indistinguishable at this precision. __So the carrier needs one hole pattern, placed twice__: two M2 clearance holes at 20.58 mm centres.

__What differs is not the pattern but its orientation.__ The BMP388's holes sit on the edge opposite its single 8-pin row; the LSM6DSO32's sit on its __Aux__ edge with the Primary row opposite. Same drill pattern, different rotation on the board.

__X positions, derived from the outline and the 2.54 mm pitch — no further measuring:__

| | Span | Inset per end, if centred |
|---|---|---|
| Mounting holes, both boards | __20.58__ | __2.46 mm__ |
| LSM6DSO32 Primary row, 9 pins | 8 × 2.54 = __20.32__ | 2.59 mm |
| BMP388 row, 8 pins | 7 × 2.54 = __17.78__ | 3.86 mm |

> __The holes do not line up with the end pins, and it is close enough to assume they do.__ At 2.54 mm pitch the LSM6DSO32's 9-pin Primary row spans __8 × 2.54 = 20.32 mm__ against a hole spacing of __20.58__. The holes sit __0.13 mm outboard of the end pins on each side__ — a real offset, and one that will not be visible by eye. Do not snap the footprint's holes to the end pads.

__Hole diameter is not an open question.__ The fastener is __M2 across the project__ (operator, 2026-09-05) — M3 does not fit these breakouts and nothing 2.5 mm is being bought. Footprints are drawn for __M2 clearance__, not for whatever a given board's hole measures.

## The Y offsets — measured 2026-09-06, both boards the same

Read off the parts by the operator, *"as best as I can do on these parts"*:

| | Reading |
|---|---|
| Header row centreline → near long edge | __2.54 mm__ |
| Header row centreline → far long edge | 15.75 mm |
| Mounting-hole centreline → far long edge | __14.65 mm__ (so __3.15__ from the near edge) |
| Mounting hole → each short side | __2.54 mm__ |

__Both boards read the same__, which is consistent with everything else: same outline, same pattern, same thickness.

### One pair closes and one does not

__The mounting-hole readings close exactly.__ 14.65 + 3.15 = __17.80__, the measured width. Take those as good.

__The header pair does not.__ 2.54 + 15.75 = __18.29__ against a 17.80 width — __0.49 mm over__, so one of the two is not an edge-to-centre reading. __Use the 2.54__: it is the short, easy reading, it sits on the 0.1 in grid these boards are laid out to, and the far edge then derives as __15.26 mm__. The 15.75 is most likely taken to the far side of the hole rather than its centre.

### The hole spacing has two routes and they differ by 0.16 mm

- From the short-side inset: 25.50 − 2 × 2.54 = __20.42 mm__
- Measured across the holes directly: __20.58 mm__

__0.16 mm, and that matters more than it looks.__ An M2 in a Ø2.35 hole has __0.35 mm of total clearance__, so a 0.16 mm error in hole spacing consumes __46% of it__ before any fabrication or print tolerance is added. It will very likely still assemble; it is not comfortable.

__Worth one tie-break reading before the board is fabricated__, not before the footprint is drawn: outside-edge to outside-edge across both mounting holes, minus one hole diameter. Whichever number that supports becomes the footprint's. Until then the footprint is drawn on __20.58__, the direct measurement of the thing that actually matters.

__Nothing further is needed to draw the footprint.__ Outline, pitch, hole pattern and both Y offsets are in hand, and every X position falls out of the outline and the 2.54 mm pitch.

__This tie-break no longer gates fabrication__ (2026-09-11): nothing screws a sensor into the carrier any more. The holes only take the BMP388's M2 leg bolts, which rest on the board, so 0.16 mm does not matter.

## XIAO ESP32S3 — read off the underside 2026-09-08

__The pinout the whole carrier netlist rests on, and until now it was never verified.__ Read off [`XIAO-ESP32-S3-bottom.jpg`](resources/XIAO-ESP32-S3-bottom.jpg) — the labels are on the __underside__, which is why the earlier top-face photo could not settle it.

Underside view, USB-C at the top. __The columns are mirrored from the top view__, which is the trap:

```text
left  column, top -> bottom    5V   GND  3V3  D10  D9  D8  D7
right column, top -> bottom    D0   D1   D2   D3   D4  D5  D6
```

So the numbering runs __D0..D6 down one side, then D7, D8, D9, D10, 3V3, GND, 5V back up the other__:

| Pin | Label | | Pin | Label |
|---|---|---|---|---|
| 1 | __D0__ | ← USB end → | 14 | __5V__ |
| 2 | D1 | | 13 | __GND__ |
| 3 | D2 | | 12 | __3V3__ |
| 4 | D3 | | 11 | D10 |
| 5 | D4 | | 10 | D9 |
| 6 | D5 | | 9 | D8 |
| 7 | __D6__ | ← far end → | 8 | __D7__ |

__Three things this confirms, none of which had been checked:__

- __`RF_Module:MCU_Seeed_ESP32C3`'s geometry is correct for an ESP32-__S3__ board.__ `gen_carrier.py` takes its pad grid from a __C3__ footprint while the parts in hand are S3. The XIAO form factor is standard across variants — but that was an assumption, and this is the reading that supports it.
- __`XIAO_PIN` in `gen_carrier.py` matches the silkscreen__, so [#18](https://github.com/jwilleke/js-rocket-avionics/issues/18)'s fix lands the nets on the right physical pins, not merely on the right footprint pads.
- __Pin 1 = D0 sits at the USB-C end__, so the USB-C faces __aft__ on the carrier. [#1](https://github.com/jwilleke/js-rocket-avionics/issues/1)'s charging pigtail depends on that and had been resting on an inference.

__Also visible and consistent with [XIAO-ESP32S3-cam.md](../hardware/XIAO-ESP32S3-cam/XIAO-ESP32S3-cam.md):__ `BAT+`/`BAT−` are __centre pads on the underside__, not on the castellated edge — which is why the battery reaches each board by soldered pigtail rather than through the headers. The JTAG pads (`MTCK`, `MTDO`, `MTDI`, `MTMS`) sit between them.

## What is left

__Every part is in hand, and every part has an owner__ — a [hardware page](../hardware/README.md), which also indexes the grid photographs. Nothing here is waiting for a part to arrive.

- __Nothing is owed on the sensors.__ The LSM6DSO32's Aux row was measured off the photograph at 12.70 mm (above), and the hole-spacing tie-break no longer gates anything. The same measurement puts the holes at ~20.4–20.5 mm, leaning to 20.42
- __[L76K-GNSS](../hardware/L76K-GNSS/L76K-GNSS.md) has a pin order__, from Seeed's schematic (2026-09-10), __and the part is confirmed as V1.1__ off its own bottom silkscreen (operator, 2026-09-11), so Seeed's V1.1 drawing is the part in hand. The pads are the XIAO's pattern, and only D6, D7, 3V3 and GND are used; the table is on the part's page, which owns it — [#6](https://github.com/jwilleke/js-rocket-avionics/issues/6), [#14](https://github.com/jwilleke/js-rocket-avionics/issues/14)
- __[PS1240-buzzer](../hardware/PS1240-buzzer/PS1240-buzzer.md)__ — two pins. Nothing to read off it

__There is no reed switch__ — [Arming-switch.md](../hardware/Arming-switch/Arming-switch.md) owns what replaced it and why.

Purchase history is in [shopping-list.md](shopping-list.md).

## The mounting-orientation question

Both sensors put their header on __one edge only__. Two ways to mount, and it is a real 2c decision:

- __Perpendicular__ — header into the carrier, board standing up. Simple, but ~17.8 mm tall plus header against __19.7 mm__ available at the bore centre, and __cantilevered off the header alone__.
- __Flat__ — board parallel to the carrier, standing on its header pins, with the mounting holes doing the rest of the mechanical work. Lower and far better for shock.

__Flat is the answer, and the calipers settled it.__ On the BMP388 the two mounting holes sit at the corners of the edge *opposite* the header, with the Qwiic connectors on the short sides — confirmed on the part. Screws at one end and a soldered header at the other gives __two-point restraint__ across the board, exactly what boost loading wants and what perpendicular mounting cannot offer.

Flat also wins on height now that the board is measured. It stacks __4.79 mm__ plus standoff against the __19.7 mm__ available at the bore centre; perpendicular would stand 17.8 mm of board plus header into that same 19.7 mm, cantilevered off the header alone.

### The header is a straight kit-standard strip — settled 2026-09-08

__Straight headers. Not right-angle, not links.__ The board stands on its pins at the header's own __~2.50 mm__ standoff, parallel to the carrier, with __M2 spacers of the same height__ under the two mounting holes. Header edge and screw edge at the same height is what makes it flat.

__This design already does exactly that.__ A XIAO mounts flat on two straight 1×7 strips — see [Stacking-headers.md](../hardware/Stacking-headers/Stacking-headers.md) and [design.md](design.md). A sensor is the same problem with one header row instead of two, the screws standing in for the second row.

Right-angle would only be needed to lie a board flat with the header entering from the *side*, and nothing here asks for that. __An earlier revision of the bullet above offered "right-angle headers or short links" and never chose between them__; that clause appeared once, propagated to no part page, and was read as an open decision it was never intended to be. It is closed: the strips in the kit are the part, for the bench and for flight, __soldered once and never removed__.

Height, for the record: 4.79 mm board + 2.50 mm standoff = __7.29 mm__ off the carrier, against 10.72 mm for XIAO-ESP32S3-cam on the same face. The sensors do not set the height budget.

__Footprint inputs, from the part:__ two Ø2.35 mm holes at 20.58 mm spacing, __M2 screws__. See [BMP388 — measured](#bmp388--measured-2026-08-08) above. __The LSM6DSO32 was expected to share this form factor and does not__ — it carries two header rows and puts its mounting holes on the same edge as one of them (see above). The two-point restraint argument still holds, on the Aux edge rather than the header-opposite edge. __Its readings are above__ ([LSM6DSO32](#lsm6dso32--read-off-photographs-2026-09-05-not-off-calipers)), taken off the grid rather than with calipers.

## Before designing a footprint round any module

__Confirm the silicon matches the label.__ Clone listings copy Adafruit's product text verbatim and the chip does not always match.

- BMP3xx `reg 0x00` → __0x50 = BMP388__, 0x60 = BMP390. A __BMP280__ answers __0x58__ at `reg 0xD0`.
- __Photograph the header pin order__ with the part in front of you, as was done for the BMP388 above. That order is the footprint input.

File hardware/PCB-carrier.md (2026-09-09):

# Carrier PCB

__The only part here that is also structure.__ One board on the sled's centre plane, parts on both faces — and __the sled's structural span__, because the printed web is only 3 mm and is explicitly *not* the structural member.

The frozen interface is in [README.md](../README.md). This page is what the board is and what is still missing from it.

## The shape is forced, not chosen

| | |
|---|---|
| Size | __24 × 95 mm__ |
| Stackup | __4-layer__, solid ground plane |
| Thickness | __1.0 mm FR4__ |
| Nets | ~__9__ — GPS TX, GPS RX, SDA, SCL, buzzer, 3V3, GND, BAT+, BAT− |

## Three voltages, and only one of them is on this board

| Rail | Volts | Where it comes from | On the carrier? |
|---|---|---|---|
| __USB / VBUS__ | __5.0__ | A USB-C lead, only while one is plugged in | __No__ — it exists on each XIAO's `5V` pin (pin 14) and nowhere else. [LiPo-500mAh.md](LiPo-500mAh.md) notes the consequence: *on battery power there is no voltage on the 5V pin* |
| __Cell__ | __3.7 nominal__ | The [LiPo](LiPo-500mAh.md), to a JST, then by soldered pigtail to each XIAO's underside __BAT pads__ | Only as `BAT+` / `BAT−` at the JST. It does __not__ reach the headers |
| __Logic__ | __3.3__ | Each XIAO's own regulator, out of its `3V3` pin (pin 12) | __Yes — this is the board's power net.__ It supplies the sensors and the buzzer |

__So the carrier is a 3.3 V board.__ 5 V appears on it only if something is wired to a XIAO's `5V` pin, and nothing should be: the [LSM6DSO32](LSM6DSO32.md) and [BMP388](BMP388-barometer.md) are 3.3 V parts, and [module-pinouts.md](../docs/module-pinouts.md) records that the BMP388 in hand is __marked 3 V__ with 5 V no longer a documented fallback.

__Charging is 5 V, and it is not this board's business.__ Both XIAOs carry their own charger and sit in parallel on the one battery — charge through one USB port at a time. No charge IC is added here.

## How power actually reaches everything

__Nothing on this board is powered by the battery. Everything is powered by a XIAO.__ The carrier is wiring, not a power supply — it carries no regulator. The 3.3 V travels __out__ of the microcontrollers and __into__ the board, which is backwards from how a carrier usually reads and is why this section exists.

```text
  LiPo 3.7 V
     |
     |  2 wires
     v
  JST-PH on this board ---- BAT+ / BAT-
     |
     +-- soldered pigtail --> XIAO-ESP32S3-cam    underside BAT pads
     +-- soldered pigtail --> XIAO-ESP32S3-lora   underside BAT pads
                                    |
                           each XIAO has its own charger
                           and its own 3.3 V regulator
                                    |
                                    v
                           3V3 pin 12  --+
                           GND pin 13  --+  back OUT through the header
                                          |
                                          v
                              this board's +3V3 and GND planes
                                          |
                              +-----------+-----------+
                              v                       v
                         LSM6DSO32                 BMP388
```

__Why the pigtails exist.__ `BAT+`/`BAT−` are __centre pads on the XIAO's underside__ ([module-pinouts.md](../docs/module-pinouts.md#xiao-esp32s3--read-off-the-underside-2026-09-08)), not on the castellated edge, so the battery cannot reach a XIAO through the header. Two soldered wires are forced, not chosen.

__What the +3V3 plane actually feeds: two parts.__ [LSM6DSO32](LSM6DSO32.md) and [BMP388](BMP388-barometer.md). The [PS1240 buzzer](PS1240-buzzer.md) is not on that list — a passive piezo is driven straight off `D0` and GND and takes no supply rail.

__Everything else is powered by the XIAO it plugs onto__, through that module's B2B connector, and never touches this board:

| Part | Powered by |
|---|---|
| [Wio-SX1262](Wio-SX1262-LoRa.md) | XIAO-ESP32S3-lora |
| [L76K-GNSS](L76K-GNSS.md) | XIAO-ESP32S3-lora, __flat on the top face__ |
| [Sense-camera-board](Sense-camera-board.md) | XIAO-ESP32S3-cam |
| Camera module, [microSD](microSD.md) | the Sense board |

### Charge through the Sense stack, and only that one

__Operator, 2026-09-08.__ For charging alone it makes no difference — both XIAOs have a charger and both sit on the same battery. __The decision is about which port is permanently committed__, because [#1](https://github.com/jwilleke/js-rocket-avionics/issues/1)'s service pigtail occupies whichever one it is wired to:

- __[XIAO-ESP32S3-cam](XIAO-ESP32S3-cam.md), the Sense stack__ — the aft module, so the shortest cable run; the only one that reaches the microSD; and the one being reflashed constantly, since its firmware does not exist yet
- __[XIAO-ESP32S3-lora](XIAO-ESP32S3-lora.md)__ — runs __stock Meshtastic and must never be reflashed__. That is the whole reason there are two modules. A service port on it invites exactly what the two-module split exists to prevent

__So XIAO-ESP32S3-lora's USB-C is not used in the flight build.__ It is reachable only by taking the nose apart.

__And still one at a time.__ Two chargers on one battery will argue; nothing enforces this but the build order.

### Two regulators on one net, which nobody chose deliberately

Both XIAOs' `3V3` pins land on the __same +3V3 plane__, so their regulators run __in parallel__. Linear regulators do not share load: whichever holds the marginally higher output supplies everything until it current-limits, and if one module ever loses its pigtail the other back-feeds into its regulator output.

It will very likely be fine at these currents. __It is recorded here because it is a consequence of the layout rather than a decision__, and [#4](https://github.com/jwilleke/js-rocket-avionics/issues/4) is benching the shared battery anyway — it costs nothing to measure both rails in the same sitting. The regulator type is assumed rather than read off Seeed's schematic.

__Why not two smaller boards.__ The twin-PCB plan assumed each XIAO could sit flat on its own card with a cutout clearing the expansion board underneath. The XIAO's own footprint kills it: pads at __±8.5 mm__, expansion board at __±8.75 mm__. __The thing needing clearance is wider than the pads are apart__, so any cutout large enough to pass it removes the copper the pads solder to. No geometry satisfies both.

__Why not 24 × 70.__ The two XIAOs cannot overlap in plan view — they mount on __through-hole__ headers, and XIAO-ESP32S3-lora uses D6/D7 for the GPS UART where XIAO-ESP32S3-cam uses D4/D5 for I2C. Different nets, same holes. So they sit end to end, and at 24 mm wide against 17.8 mm sensors nothing sits side by side:

```text
top face     XIAO-ESP32S3-lora 21 + L76K 21, end to end              = 42 mm
bottom face  XIAO-ESP32S3-cam 21 + LSM6DSO32 25.5 + BMP388 25.5 + buzzer = 84 mm
```

__The bottom face sets the length, through every revision of the top one.__ 46 mm with a MAX-M10S on the carrier, 21 mm with the L76K riding the stack, __42 mm__ now the L76K is flat on the carrier (2026-09-09). 84 mm on the bottom drove the board in all three cases, so __nothing about the frozen interface moves and the sled does not reprint__ — 53 mm of the top face is still free.

## Population

| Face | Carries |
|---|---|
| Top | XIAO-ESP32S3-lora + Wio-SX1262 __above it, on its front-face B2B__; __L76K flat on the carrier__, end to end |
| Bottom | XIAO ESP32S3 Sense + camera/microSD board __above it, on its front-face B2B__; LSM6DSO32; BMP388; buzzer |
| Either | Battery JST, arming switch in the battery line, mounting holes |

__XIAO B centres at carrier y = 18 mm__, which is what puts the camera at nose z 30..45.

## Build rules

- __4-layer, solid ground plane.__ A few dollars more at this size; fixes return paths and coupling from the camera's DVP flex
- __Module footprints, not bare chips.__ A bare LSM6DSO32 is an LGA-14 at 2.5 × 3 mm and is not hand-solderable. Soldering breakouts down still gives one rigid assembly with no flying wires — apart from the two battery pigtails, which are unavoidable
- __Solder or clamp the headers — no loose sockets.__ Battery straps to the sled, never hangs off the JST. Conformal coat after bench testing
- __The battery pigtails are anchored to the board, not held by their solder joints.__ 2.3 × 1.3 mm pads will lift if the joint is the mechanical restraint. Wire spec, the adhesive anchor and the routing through the 2.50 mm gap are in [LiPo-500mAh.md](LiPo-500mAh.md#the-pigtail-is-the-fragile-part-and-the-solder-joint-must-not-be-the-anchor), which owns them
- __Silkscreen which face is which__, and mark the pigtail polarity — reversing a LiPo into a XIAO destroys it
- __≥50 mm antenna separation__, through routing as well as placement

## Where it actually is

[README.md](../README.md) reports __2a complete, 2b partial, DRC clean at 0 violations, 0 unconnected__ — true, and easy to over-read. What exists is the outline, stackup, mounting holes, planes, and both XIAO positions with their nets.

| Stage | State |
|---|---|
| 2a — outline, mounting holes, stackup | __done__ |
| 2b — nets and footprints | __partial__ — XIAOs placed and netted, [#18](https://github.com/jwilleke/js-rocket-avionics/issues/18) fixed and closed 2026-09-08 (`c2468eb`: the +8.5 row unmirrored, and `verify_pins()` now asserts every net against the footprint's own pin table on each run). Sensors, buzzer and JST still deferred to [#14](https://github.com/jwilleke/js-rocket-avionics/issues/14) |
| 2c — placement | blocked on measured module pinouts — [#14](https://github.com/jwilleke/js-rocket-avionics/issues/14) |
| 2d — routing | __not started__. Autorouting is wrong here — [#15](https://github.com/jwilleke/js-rocket-avionics/issues/15) |
| 2e — gerber + drill export | chain proven; needs a finished board |

> __`fab/gerbers/` already holds a complete-looking set, and it is a partial board wearing a finished package.__ Generated by `hardware/scripts/gen_carrier.py` from a board with no sensor footprints, no `VBAT` and no routing. It is the single most likely way a wrong board gets ordered — it is complete, it is in the repo, and it looks done. __Regenerate, never reuse__ — [#16](https://github.com/jwilleke/js-rocket-avionics/issues/16).

## Read the board, not the script

An earlier generator revision put GPS on pins 6/7 and I2C on 4/5 — __D5/D6 and D3/D4, every one off by one__. It was caught by __reading the mapping back out of the saved board__, not by trusting the script's output. The generator now names pins (`XIAO_PIN["D6"]`) so the numbers never appear by hand.

> __It happened again, and this section is why that stings.__ [#18](https://github.com/jwilleke/js-rocket-avionics/issues/18), found 2026-09-08: the whole `+8.5 mm` row is mirrored end for end, so `+3V3` and `GND` land on __D9 and D8__ and `GPS_RX` on the __5V pin__. Naming the pins fixed the arithmetic and did nothing about the row order.
>
> __The read-back was written down as the check and never made routine.__ That is the actual defect — a check that only runs when someone remembers is a check that catches the first instance and not the second.
>
> __Now it runs.__ `c2468eb` closed [#18](https://github.com/jwilleke/js-rocket-avionics/issues/18) by unmirroring the row *and* adding `verify_pins()`, which asserts every placed net against `MCU_Seeed_ESP32C3`'s own pin coordinates on every generate — checking __both__ x and y, because pins 7 and 8 share a y and only x tells the two rows apart. A third instance fails the build rather than waiting for someone to read the board.

## Ordering

__Do not order copper before breadboarding.__ A layout error costs ~$33 and __two weeks__; a wiring error costs minutes. The gate is [#4](https://github.com/jwilleke/js-rocket-avionics/issues/4); the ordering epic is [#11](https://github.com/jwilleke/js-rocket-avionics/issues/11). Three copies from OSH Park.

__The outline and mounting-hole pattern were frozen before the sled generator was written__, since the sled's rail bosses derive from them. Moving them reprints a part.

---

Part numbers, vendors and masses live in [BOM.md](../docs/BOM.md), which is the single source of truth for both. Purchase history is in [shopping-list.md](../docs/shopping-list.md); the reasoning is in [design.md](../docs/design.md).

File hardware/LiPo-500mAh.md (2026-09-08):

# LiPo battery

__One battery feeds both MCUs.__ Over an hour against a ~300 mA draw.

## The part

| | |
|---|---|
| Body | __29 × 36 × 4.75 mm__ — verified against the part, 2026-09-07 |
| Mass | __10.9 g__ with its pigtail — weighed. Adafruit's label says 10.5 |
| Leads | __80 mm__ measured, JST-PH. Adafruit's page says 102 — __the 80 is what governs__, and it is the number the JST's position on the carrier is set by |
| Output | 500 mAh at 3.7 V nominal |
| Vendor | [Adafruit 1578](https://www.adafruit.com/product/1578) |

__It is the largest single object in the nose__, and until 2026-09-07 this page recorded no dimension at all, so nothing about packaging could be settled.

### Where it goes — OPEN. Two candidates, neither chosen

__Nothing here is decided.__ Both positions below are live as of 2026-09-07 and the arithmetic for each is recorded so the choice can be made on numbers. The two differ on __access versus stability__, and they pull opposite ways.

#### Candidate A — on the carrier's top face, inside the Nosecone

The face carries only XIAO-ESP32S3-lora's 21 mm of the carrier's 95, so __74.0 mm is clear__. A 29 mm wide object has __13.34 mm__ of radial room from the centre plane; the battery needs 0.5 + 4.75 = __5.25__, against the lora stack's 12.32. It sits alongside, not on top of anything.

- __Keeps the mass forward__, at station ~184–220, which is where the stability case wants it
- __29 mm wide on a 24 mm web__ means 2.5 mm of overhang each side. The straps carry it, but the battery is wider than the thing it straps to
- __Costs access.__ Changing the battery means pulling the sled: out comes the M3 × 55, off comes the nose, and the sled is pushed out from below with a rod — which re-cycles the rib crush, disturbs the 8.5 mm camera ribbon and loses the camera's aim. That is the complaint in [#1](https://github.com/jwilleke/js-rocket-avionics/issues/1)

#### Candidate B — in the PayloadAdapter's bore, below the nose joint

About __adapter z 2..38__ — nose z −38..−2, station __242..278__ from the tip. __It fits with room to spare__: the adapter's bore is __Ø35.75__ over adapter z 0..30, opening to Ø39.98 at z 34..40, so a 29 mm wide slab has __20.91 mm__ of thickness available against the battery's 4.75, and the 36 mm length sits inside the ~40 mm of clear bore below the Nosecone's tenon.

- __Buys the access outright.__ Pull the nose, unclip the JST, battery out, __sled untouched__ — [#1](https://github.com/jwilleke/js-rocket-avionics/issues/1) answered rather than mitigated
- __Takes arming off the sled with it.__ Flight 3 carries __no [arming switch](Arming-switch.md)__, so there is nothing on the sled to take off it; any later switch sits __in series in the battery line between the battery and the carrier JST__, so it follows the battery onto the airframe, and the sled's 180° flip — which [js-rocket#90](https://github.com/jwilleke/js-rocket/issues/90)'s loop reduced but did not remove — stops bearing on arming at all
- __Nothing retains it.__ The M3 × 55 cross-bar is at adapter z 55, __17 mm above__ the battery's top, so it does not hold it down, and below the battery the bore runs straight through into the Tube. The Nosecone page already records the general case — *"the bay is open at its base, so with the nose fitted a payload drops through into the Tube. Needs a retainer (plug, foam, tape) or a lip"*
- __It sits in the recovery cord's path.__ The M3 is the cord's upper anchor and the cord runs down that bore, so ejection whips the bungee past exactly where the battery is. A LiPo pouch is 4.75 mm of soft foil, and a crushed or punctured battery is a fire inside a sealed nose on a rocket that has to be picked up by hand. __Any retainer here must also shield it from the cord__ — a sleeve, a tube or a hard divider — not merely stop it falling
- __It contradicts [`payload-adapter.md`](https://github.com/jwilleke/js-rocket/blob/main/docs/3d-printed-parts/payload-adapter.md)__, which states twice that *"it is an adapter, not a payload bay — the payload lives entirely in the Nosecone."* That sentence has to be replaced deliberately, not simply overtaken

#### What decides it

__Access is worth a lot and the mass move is not free.__ B shifts 10.9 g from station ~184–220 to __242–278__, aft of the sled's own aft end at 223.1. The lever is already measured on the sled: ballast at its forward end needs __30.9 g__ and at its aft end __62.7 g__ for the same 1.5 cal — the requirement doubles over 134 mm. So 10.9 g moved 40–90 mm aft is not negligible in the currency this project already uses, and __the separated sustainer is the binding case at 0.34 cal__, needing 59.6 g at station 100.

Nose mass would drop 10.9 g under B, taking the nose total from 54.6 to 43.7 and under the ~50 g target — __but the mass has not left the rocket, only moved aft__, so that is bookkeeping rather than a saving.

__Re-run [`stability-flight3.py`](https://github.com/jwilleke/js-rocket/blob/main/rocket/scripts/stability-flight3.py) with the battery at station ~260__ and the trade becomes a number instead of a direction ([js-rocket#66](https://github.com/jwilleke/js-rocket/issues/66)). That is the missing input, and it is cheap.

### The 80 mm lead, and what it constrains under each candidate

__Under A__ the run is short and 80 mm imposes nothing.

__Under B__ it is the binding dimension. The lead climbs the bore, passes the M3 cross-bar at nose z 15, and has to get through the sled's aft end disc — 39.4 mm with ribs to 40.2 in a 40.0 mm bore, effectively sealed. __The only gap is the D-flat crescent at azimuth 180__, so that crescent would be not a convenient wire route but the only one, fixing the pigtail's azimuth. Battery top would sit at __nose z −2__; allowing 15–25 mm for the bends and that route, 80 mm reaches __nose z 53..63__, against a carrier spanning roughly nose z 20..115.

> __So B puts the JST in the aft third of the carrier__, within about __35–45 mm of its aft end__. A is indifferent. __Placing the JST aft satisfies both__, which makes it the cheap hedge while the position is open — and it is free now and a respin to discover later ([#14](https://github.com/jwilleke/js-rocket-avionics/issues/14), stage 2c).

__An inline arming switch would eat into the same 80 mm under B — and flight 3 has none__ ([Arming-switch.md](Arming-switch.md), 2026-09-08), so the 80 mm is the JST's alone and __its position is decided on its own__. If a later flight adds a switch, this coupling comes back and the two are decided together.

### Ruled out on geometry, under either candidate

__Behind the sled's D-flat.__ The crescent between the flat and the bore looks like the obvious home — 8.00 mm deep, 32.00 mm across at its mouth — but it is a circular segment and closes fast. At the battery's own 4.75 mm of thickness the chord is down to __21.86 mm__, and a 29 mm width survives only __1.77 mm__ of depth. No orientation rescues it: 36 mm is worse than 29, and standing it on edge needs 29 mm of depth against 8.00 available. The crescent's use is wiring, the arming pin and the buzzer's air path.

__The free web.__ The web is 124.0 mm and the carrier takes 95.0, leaving __29.0 mm__ against a 36 mm battery.

## Distribution

The battery lands on a __JST-PH on the carrier__ — put it in the carrier's aft third, which serves both candidate positions above — and short __soldered pigtails__ run to each XIAO's underside BAT pads. That indirection is forced, not chosen: __BAT+/BAT− are not on the castellated edge__, so the battery cannot reach a XIAO through the headers.

- __Solder the pigtails before the XIAO goes onto its headers.__ Not before the expansion board — that mates to the *front* face and never covers the pads. What covers them is the __carrier__, at the header's 2.50 mm, and the breadboard does the same on the bench. Faces and evidence in [XIAO-ESP32S3-cam.md](XIAO-ESP32S3-cam.md#which-face-carries-what--settled-off-seeeds-two-drawings-and-the-stack-itself)
- __Both XIAO chargers sit in parallel on one battery — charge through one USB port at a time.__ This avoids adding a charge IC
- __On battery power there is no voltage on the 5V pin__
- __Reversing a LiPo into a XIAO destroys it__ — [design.md](../docs/design.md) requires the pigtail polarity be silkscreened
- __The battery is mechanically restrained, never hangs off the JST.__ On the sled that is the straps; in the adapter nothing does it yet. __The JST is a connector, not a mount__, whichever position wins

### The pigtail is the fragile part, and the solder joint must not be the anchor

__`BAT+`/`BAT−` are 2.3 × 1.3 mm pads.__ That is an electrical connection, not a structural one. If the joint is what holds the wire, boost and landing put the load into the pad, and __the pad lifts__ — taking the copper with it and leaving nothing to re-solder to.

So the wire is anchored to the board, and the joint carries current only:

- __28–30 AWG fine-stranded, silicone insulated. Never solid core.__ Solid wire work-hardens and snaps at exactly this kind of joint; stranded silicone stays flexible and takes vibration without transmitting it
- __Bond the wire to the PCB 3–5 mm from the pad__, with UV-cure or two-part epoxy. __This is the actual fix__ — everything else on this list is secondary to it. It puts the flex point in the free wire instead of on the copper
- __Leave a service loop.__ Slack, so nothing is ever in tension. A taut pigtail is a pigtail under load whenever anything moves
- __Dress it through the 2.50 mm gap__ between the XIAO's back face and the carrier — clear of the header pins, and not lying on carrier copper. Route and tack it __before__ the XIAO goes down; there is no access afterwards
- __Conformal coat over the finished joint__, after bench testing, with the rest of the board
- __Polarity silkscreened at the JST__ — reversing a LiPo into a XIAO destroys it

> __A broken pigtail is silent.__ With both `3V3` pins on the same plane, the surviving regulator back-feeds the dead module and the rocket still works — so the first failure hides the fault and only the second one grounds you. __Inspect both joints as a step, rather than waiting to be told about them.__ It is also the strongest argument for keeping the plane tie until [#8](https://github.com/jwilleke/js-rocket-avionics/issues/8) says otherwise.

__No connector at the pad end.__ A connector there would put mass and leverage on the weakest joint in the assembly, which is the opposite of what is wanted. The disconnect belongs at the far end and already exists — the JST.

## The known risk, still unobserved

[BOM.md](../docs/BOM.md) accepts a coupling failure in writing: __*"a camera brownout on B can disturb A."*__ [design.md](../docs/design.md) repeats it — separate batteries would isolate the boards but cost ~8 g the mass budget cannot afford.

__That is a prediction, not a measurement, and the thing it threatens is the radio link.__ A camera write that resets XIAO-ESP32S3-lora mid-descent costs the rocket, not the video. Settling it is [#8](https://github.com/jwilleke/js-rocket-avionics/issues/8) — run both boards off one battery with the camera active, on a __partially discharged battery__ where sag is worst, and produce a verdict: acceptable, needs decoupling on the carrier, or needs the second battery after all.

__If decoupling is the answer it lands in the layout before the board is ordered__, not after.

## Rejected

__An 18650__ would put nose mass near the ~65 g weathercock limit.

---

Part numbers, vendors and masses live in [BOM.md](../docs/BOM.md), which is the single source of truth for both. Purchase history is in [shopping-list.md](../docs/shopping-list.md); the reasoning is in [design.md](../docs/design.md).

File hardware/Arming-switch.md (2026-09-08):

# Arming switch

__Flight 3 flies without one__ (operator, 2026-09-08). In the battery line, not on a GPIO, whenever a flight does carry one. Nothing was chosen, nothing was bought, and nothing was waiting on it.

> __So flight 3 has no arming device at all__ — the part named by this page is the arming device, and it is deferred rather than replaced. __Nothing else is promoted into the role.__ Power is made and broken by plugging and unplugging the [battery](LiPo-500mAh.md)'s JST, which is a __connector__ and stays one; giving it a second name would put a safety role on a part that was never designed to carry it, and this project keeps one name per part.
>
> __What that costs is turnaround, not safety.__ This payload has no pyro, so an "armed" rocket here is one that is recording video. The switch only ever bought a faster way to reach the disconnect; the argument below is unchanged and kept for whenever a flight wants it.
>
> __What it buys back, today:__ the 80 mm battery lead no longer has to carry an inline switch, so __the JST's position is decided on its own__ rather than jointly — see [LiPo-500mAh.md](LiPo-500mAh.md). One less coupling in [#14](https://github.com/jwilleke/js-rocket-avionics/issues/14) stage 2c.
>
> __The pad procedure this forces:__ runtime is ~100 minutes from the moment the battery is connected and it cannot be managed in firmware, so __the JST goes on last__, on the pad, and the clock starts there.
>
> __What would overrule it__ is unchanged and still unchecked: a club or field rule requiring a visible external arming switch for any powered electronics. A rule beats an argument.

## It is not a safety device on this rocket, and calling it one drove requirements it does not need

__An arming switch exists to stop a flight computer firing an ejection charge on the ground.__ That is why NAR and Tripoli require them and why they are normally non-negotiable.

__This payload has no pyro.__ [design.md](../docs/design.md) is explicit: *"No pyro channels; ejection is the motor delay. Apogee is data, not deployment."* The avionics __cannot actuate anything__. An "armed" rocket here is a rocket that is recording video.

So the sentence this page used to carry — *a welded switch is an armed rocket that cannot be safed, the failure mode that matters because it happens on the pad with people nearby* — __described a hazard this design does not have__. It was inherited from rocketry convention rather than derived from this rocket, and it is what produced the MOSFET, the welding analysis and the demand for a hole in the Nosecone collar.

__What is real is runtime.__ 500 mAh against ~300 mA is roughly __100 minutes__ from the moment the battery is connected, and it cannot be managed in firmware: [XIAO-ESP32S3-lora](XIAO-ESP32S3-lora.md) runs __stock Meshtastic with no code written__, which was a deliberate choice and means it cannot sleep. It draws from the instant it has power.

__So a disconnect is needed. A switch in the nose wall is not.__ The JST already is one; the only question is when it can be reached:

| | Cost of a launch delay past ~100 minutes |
|---|---|
| No switch — connect the JST last | Pull the M3 × 55 and extract the sled. That pin also anchors the recovery cord, so it is a nose teardown plus a re-rig |
| Switch in the nose wall | Flip it |

__That difference is the whole value of the switch: turnaround, not safety.__ It is worth having against the *"rapidly reusable rocket flown by a 14-year-old"* objective, and it is not worth blocking an airframe part for.

__What would overrule this:__ a club or field rule requiring a visible external arming switch for any powered electronics, regardless of deployment. A rule beats an argument. Not checked.

## The old framing, kept for what it got right

Once the nose is assembled __there is no way in__: USB is unreachable, Wi-Fi is off, and the status LED is sealed inside. A slide switch would need another hand-drilled hole in a part with no generator.

Whatever the mechanism, the architecture is settled and worth restating because it is the part that survives every revision below: __the switch sits in series in the battery line, between the battery and the carrier's JST.__ That means it __physically cuts power__ rather than setting a firmware state a boot-loop could defeat, it costs __zero GPIO__, and it __cuts both XIAOs at once__ — arming is all-or-nothing, __including the radio__.

## A pull-pin and a subminiature microswitch

__Smallest hole, snap action, no printed mechanism.__ Reasoning in the [arming brainstorm](../docs/resources/2026-08-15-arming-and-access-brainstorm.md).

> __An earlier note here said [design.md](../docs/design.md)'s locked-decisions table still named a reed switch.__ It does not, and had already stopped by the time this was read again — that row names the architecture and points here for the mechanism, which is the right division. Checked 2026-09-08.

__Nothing has been bought and no part has been chosen.__ The mass in [BOM.md](../docs/BOM.md) is inherited from the reed-switch design.

## The live constraint: contact rating against camera inrush

__Polarity is not a question with a pull-pin__ — the pin is in, the rocket is safe, and the pin doubles as a visible remove-before-flight tag. What does apply to any switch chosen:

- __Contact rating against camera inrush.__ Steady draw is ~300 mA, which is comfortable, but __the camera powering up is the question__: small contacts can weld under inrush, and __a welded switch is an armed rocket that cannot be safed__ — the failure mode that matters, because it happens on the pad with people nearby

> __The MOSFET is dropped__ (2026-09-08). It existed to stop a welded contact leaving the rocket armed. Without pyro, a welded contact means *the camera will not turn off*, which is a bench problem. __[#14](https://github.com/jwilleke/js-rocket-avionics/issues/14) no longer waits on this__, and no footprint is needed.
>
> The brainstorm had already reached the same place by a different route: many subminiature microswitches are rated __3–5 A__ against a ~300 mA draw, so the switch could carry the load directly anyway.

## Where the pin enters

__If one is ever cut, it should share [#1](https://github.com/jwilleke/js-rocket-avionics/issues/1)'s opening rather than buy a second hole.__ That issue already wants a USB-C aperture for charging, data and status, and the measurements are done — ~9 × 3.2 mm fits the exposed band of the PayloadAdapter. One hole, three jobs, plus this one.

__An earlier note here said the entry point was "set by the sled's clocking, [js-rocket#90](https://github.com/jwilleke/js-rocket/issues/90)" and could not be chosen until the sled's azimuth was fixed. That overstated what #90 delivered.__ The loop stops the sled turning freely, but a __180° flip still threads the same pin__ — a featureless rod on a diameter is symmetric — so the switch could still face either side. The `PORT` engraving is a label, not a key.

---

Part numbers, vendors and masses live in [BOM.md](../docs/BOM.md), which is the single source of truth for both. Purchase history is in [shopping-list.md](../docs/shopping-list.md); the reasoning is in [design.md](../docs/design.md).

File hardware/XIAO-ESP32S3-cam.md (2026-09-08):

# XIAO ESP32S3 — cam

__The XIAO that carries the camera.__ The copy that arrived in the Sense kit.

__This one has no headers soldered on.__ The Sense kit ships its two 7-pin strips loose. That is the only physical difference from [the lora copy](XIAO-ESP32S3-lora.md).

## What is mated to it

- __[Sense camera board](Sense-camera-board.md)__ — OV3660 camera and the microSD slot

Sensors reach it over __I2C on D4/D5__; the buzzer is __PWM on D0__. Firmware is __custom and not yet started__.

## Heights

__Datum: the bottom of the XIAO's PCB.__ Headers add __2.50 mm__ below it. Camera excluded.

| | Height | Above the carrier |
|---|---|---|
| A bare XIAO, to the top of the USB-C | __4.53 mm__ | 7.03 mm |
| __XIAO-ESP32S3-cam__ + [Sense camera board](Sense-camera-board.md) | __8.22 mm__ | __10.72 mm__ |
| __XIAO-ESP32S3-lora__ + [Wio-SX1262](Wio-SX1262-LoRa.md) | __9.32 mm__ | __11.82 mm__ |

So the Sense camera board adds __3.69 mm__ to a XIAO and the Wio-SX1262 adds __4.79 mm__.

```text
XIAO-ESP32S3-cam 10.72 + carrier 1.00 + XIAO-ESP32S3-lora 11.82 = 23.54 mm
available = 2 x sqrt(19.7^2 - 8.75^2)                           = 35.30 mm

11.76 mm spare
```

## Photograph

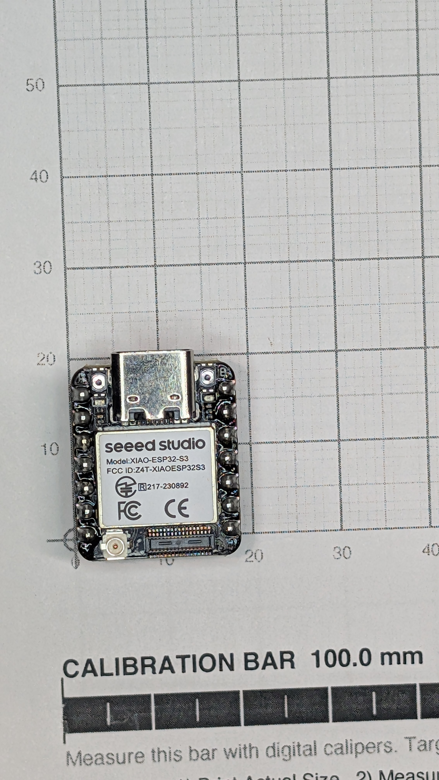
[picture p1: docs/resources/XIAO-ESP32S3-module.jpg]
XIAO ESP32S3 module on the measurement grid


## The module

Both copies are the same part — `Model: XIAO-ESP32-S3`, `FCC ID: Z4T-XIAOESP32S3` — and identical electrically. They differ only in what has been done to them and what is mated to them.

| | |
|---|---|
| Outline | __17.5 × 21 mm__ |
| Pads | __14 castellated__, two rows of 7, rows __17.0 mm apart__, pitch __2.54 mm__, pads 3 × 2 mm |
| Connectors | USB-C, __U.FL__, and the B2B connector an expansion board mates to |
| PSRAM | __8 MB__ (ESP32-S3R8) |
| Battery | __BAT+/BAT− are pads on the back face__ (footprint pads 16/17, 2.3 × 1.3 mm at x = −4.5), inboard of the `D3`/`D4` edge and __not on the castellated edge__ — see the drawing below |
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

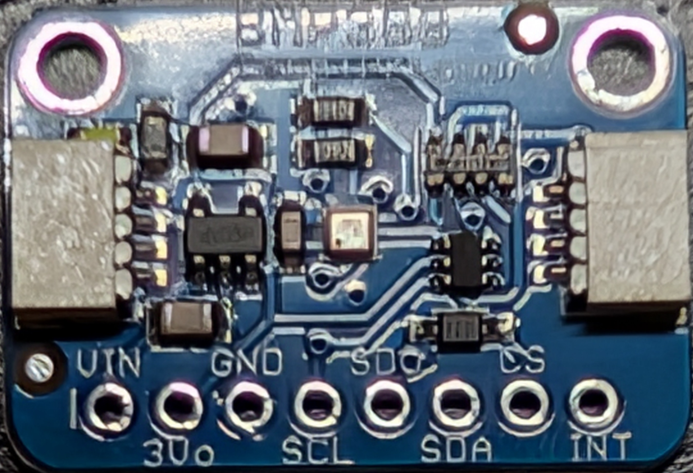
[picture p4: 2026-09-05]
hardware/BMP388-barometer/BMP388-front.jpg

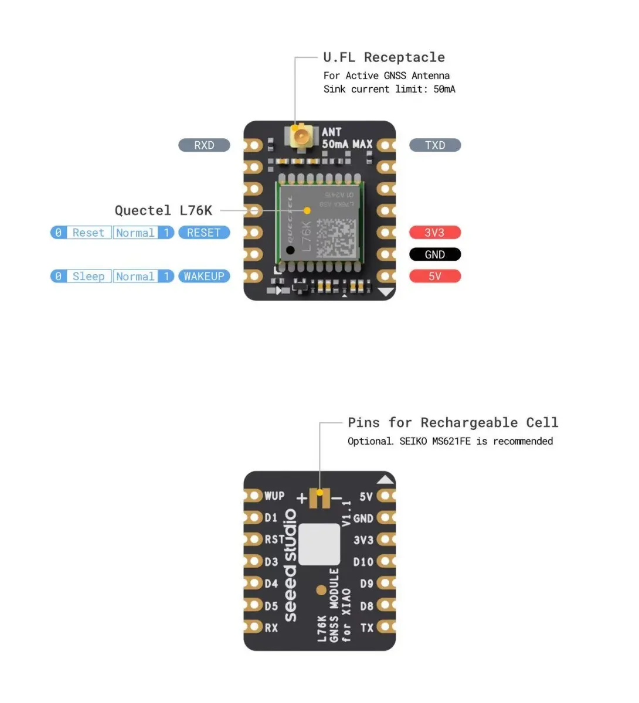
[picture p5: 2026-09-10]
hardware/L76K-GNSS/L76K-GNSS-bottom.webp

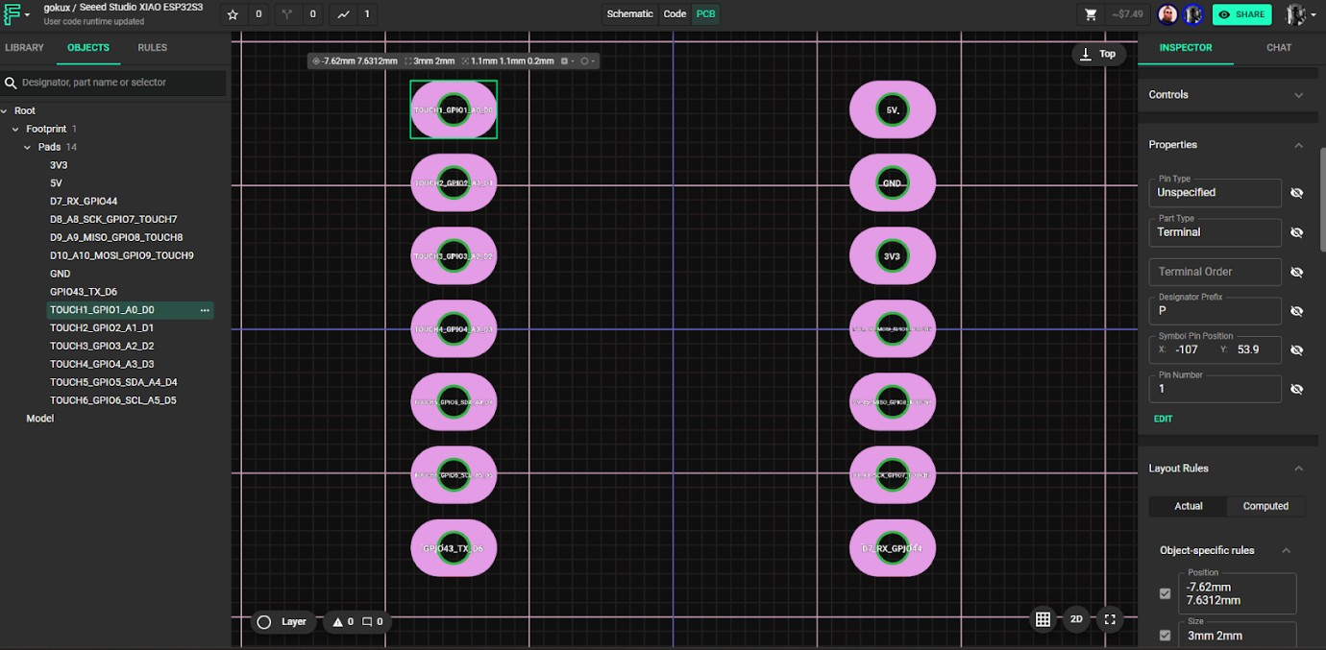
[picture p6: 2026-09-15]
hardware/XIAO-ESP32S3-cam/PCB_Design_XIAO4.png

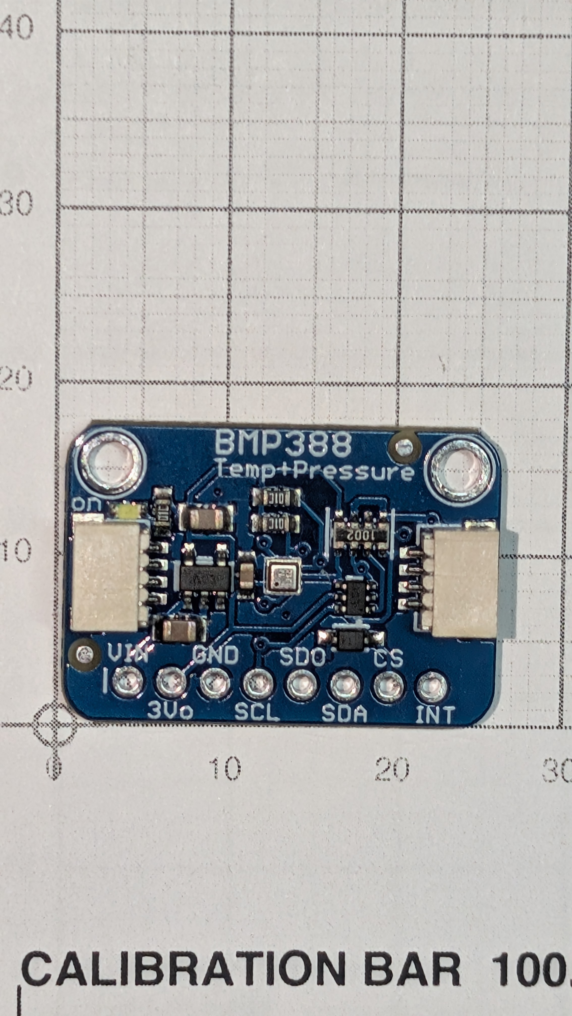
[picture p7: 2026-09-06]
hardware/BMP388-barometer/BMP388-front-grid.jpg

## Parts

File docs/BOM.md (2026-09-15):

# Bill of materials

__Single source of truth for parts, part numbers and weights.__ Anything else that quotes a part number or a mass is wrong — link here instead.

- __What to buy, order status and cost__ → [shopping-list.md](shopping-list.md)
- __Pin order and caliper readings__ → [module-pinouts.md](module-pinouts.md)
- __Why it is built this way__ → [design.md](design.md)

## Parts

Weights measured 2026-08-17 unless the row says `est`.

| Part | Part number | Vendor | Board | Weight (g) |
|---|---|---|---|---|
| XIAO ESP32S3 (plain) | 102010611 (kit) | Seeed | A | 2.9 |
| Wio-SX1262 LoRa | 102010611 (kit) | Seeed | A | 2.1 |
| U.FL 82 mm whip, 860-930M A-03 | 102010611 (kit) | Seeed | A | 0.4 |
| L76K GNSS for XIAO | 109100021 | Seeed | A | 14.2 |
| XIAO ESP32S3 Sense | 113991115 | Seeed | B | 4.0 |
| LSM6DSO32 6-DoF IMU | 4692 | Adafruit | B | 1.8 |
| BMP388 barometer | B0GSYYT1K5 | DIYmall | B | 1.8 |
| Piezo buzzer PS1240 | 160 | Adafruit | B | 0.6 |
| LiPo 3.7 V 500 mAh | 1578 | Adafruit | shared | 10.9 |
| microSD card | — held | — | B | __0.15__ |
| Carrier PCB, 4-layer 1.6 mm, 24 × 115.7, two-sided | — not ordered | OSH Park | both | est 8.3 |
| Charging on the carrier — Q1 and Q2, U1, 2.7 kΩ, 100 kΩ, 2 × 4.7 µF ([#30](https://github.com/jwilleke/js-rocket-avionics/issues/30); Q2 recommended, not decided) | Q1, Q2 __AO3401A__ (AOS); U1 __MCP73831T-2ACI/OT__ (Microchip) | Amazon — [shopping-list.md](shopping-list.md#the-charging-bench-30--ordered) | both | < 0.1, not counted |
| 7-pin header, 4 off — two per XIAO | Seeed kits — __2 pre-soldered on XIAO-ESP32S3-lora, 2 loose in the Sense kit__ | Seeed | both | __0.6__ |
| Arming switch + wiring | — not bought | — | shared | est 1.5 |
| __Avionics subtotal__ | | | | __49.3__ |
| ElectronicsSled, PLA | v7.7.0 | printed | — | __9.3?__ |
| __Nose total__ | | | | __58.6__ |

__Also in the kits and not flying:__ the 2.4G A-02 antenna, 0.3 g — the XIAO's WiFi/BLE antenna — and the __two aluminium heat sinks__ shipped with the Sense kit. The heat sinks adhere to the XIAO's top face, which is the face the expansion board mates to, and a sealed nose has no airflow for them to work with. See [XIAO-ESP32S3-Sense.md](../hardware/Sense-camera-board/Sense-camera-board.md#what-is-in-the-kit-and-what-flies).

## Ground equipment

__Not in the nose, not in the mass budget — and the rocket cannot be recovered without it.__ The beacon broadcasts its position over LoRa; a phone has no LoRa radio. Missing from this BOM until 2026-09-11 ([#23](https://github.com/jwilleke/js-rocket-avionics/issues/23)).

| Part | Part number | Vendor | Why |
|---|---|---|---|
| __Ground receiver__ (`mj-ground`) — Seeed XIAO ESP32S3 & Wio-SX1262, 3D-printed case, __2 dBi SMA antenna__. __Arrived running LoRaHUB, not Meshtastic__ — a LoRaWAN single-channel gateway set for Europe (868.1 MHz, The Things Network EU). Flashed with Meshtastic `2.7.26.54e0d8d` on 2026-09-13, the flight node's version | [B0GY4QC6GN](https://www.amazon.com/dp/B0GY4QC6GN) | Amazon | Hears the flight node on the private channel and hands the position to the phone over Bluetooth. The same hardware as the flight node; the SMA antenna is for range |
| USB power bank | any | held | The receiver has no battery of its own, going by the listing |

__The receiver must match the flight node__ — region `US`, modem preset `LONG_FAST`, and the private channel, joined by its QR code. Setting-up and the range check: [#23](https://github.com/jwilleke/js-rocket-avionics/issues/23).

__The sled's 9.3 g is disputed.__ The rocket repo weighed it at __7.1 g__ on 2026-08-07 ([sections.md](https://github.com/jwilleke/js-rocket/blob/main/docs/sections.md) note 6) and both figures claim the scale. Its geometry moved at v7.7.0, which may or may not explain 2.2 g. __Reweigh it__ — nose total is __56.4__ if 7.1 is right.

## Mass budget

| | g |
|---|---|
| Nose total | __58.6__ |
| Target | ~50 |
| Weathercock limit | ~65 |

__Over target, under the limit__ — a budget problem, not a grounding. 39.5 g of the total is weighed, __9.8 g still estimated__ — only the carrier PCB (8.3: 4.1 g at 90.4 × 1.0 mm, scaled to 115.7 mm and then to 1.6 mm on 2026-09-15) and the arming switch (1.5) are left. __The microSD card was in the table but in none of the totals__ until 2026-09-07: the subtotal ran weighed + PCB + switch and the card sat there looking counted. It is now weighed and folded in.

__The card is 0.15 g, not the 0.4 g estimated__ — and that is two readings, not one. A single card reads __0.1 g__ on a scale with 0.1 g resolution and __two read 0.3 g__, so the pair is the better number and a single card is ~0.15. The estimate was high by nearly 3×; it changes nothing, which is the point of writing it down. A payload gram displaces only __0.75 g__ of ballast, so overruns cost more than they look — see [payload-ballast.md](https://github.com/jwilleke/js-rocket/blob/main/docs/payload-ballast.md).

__The L76K is the whole overrun.__ Estimated 5.0 g, weighs __14.2__ — heavier than the battery, and larger than the next two rows combined. Four rows came in *light* (Sense −3.5, Wio-SX1262 −2.4, buzzer −1.4, XIAO −0.6) and still did not cover it. __Weigh the module without its active antenna__: if the antenna is most of the mass this is a separable choice; if not, it was mis-specced 3×.

__Both Adafruit STEMMA QT sensors are 1.8 g against a 1.0 g estimate, +80% each.__ The BMP388's overrun was not a fluke — that is what the form factor weighs.

__Nothing here is required to fly the rocket.__ [js-rocket](https://github.com/jwilleke/js-rocket) flies on ballast alone; the sled is payload.

## The two boards

| Board | MCU | Role | Firmware |
|---|---|---|---|
| __A__ | XIAO ESP32S3 (plain) | __Recovery beacon__ — GPS position over LoRa | __Stock Meshtastic, pre-flashed by Seeed. None written__ |
| __B__ | XIAO ESP32S3 __Sense__ | __Flight recorder__ — camera, IMU, barometer, PSRAM log | Custom, and not yet started |

Both ride one two-sided carrier PCB, on its tall side, with the sensors on the other. __Two MCUs, not one__, so the beacon is not gated on flight firmware being finished — the beacon *is* the recovery system, and a boot-loop at the pad cannot be fixed with the nose assembled.

## Why each part

| Part | Why this one |
|---|---|
| __XIAO ESP32S3 + Wio-SX1262__ | Supported Meshtastic device out of the box. __Must be the matched B2B kit variant__ — buy SKU 102010611 as a kit, never the two boards separately. It arrives pre-flashed, which is the entire premise of XIAO-ESP32S3-lora |
| __U.FL 82 mm whip__ | LoRa antenna, runs forward up the ogive. Included in the kit |
| __L76K GNSS__ | __Active antenna included.__ Talks UART on D6/D7 and __mounts flat on the carrier's tall side, between the two XIAOs__ (2026-09-09) — it can ride a XIAO's 14 pads, but does not. Replaced a MAX-M10S that was 44.2 × 30.5 mm and ~$60 |
| __XIAO ESP32S3 Sense__ | Recorder MCU. Carries the camera — an __OV3660__, confirmed off the ribbon 2026-09-06, not the OV2640 assumed throughout — and the microSD slot on its expansion board |
| __LSM6DSO32__ | __±32 g.__ Boost peaks at __17.6 g__, so every ±16 g part on the market clips — and a clipped boost integral destroys the velocity estimate for the whole flight. 9 KB __FIFO__ is a hard requirement |
| __BMP388__ | Unported: only jobs are timestamping ejection and detecting landing. Address __0x77__, no clash with the IMU. __Do not re-specify a BMP390__ — same driver, 8–12 week lead |
| __Piezo buzzer__ | PWM from D0. __Passive, not active__ — a real GPIO can drive multiple tones, so beep patterns read as distinct status codes |
| __Carrier PCB__ | The sled's structural span. See [README](../README.md) for the frozen interface. __Blocked behind breadboarding, deliberately__ — a layout error costs ~$33 and two weeks |
| __7-pin headers__ | Two per XIAO, onto its 14 pads in two rows __15.24 mm apart__ ([#33](https://github.com/jwilleke/js-rocket-avionics/issues/33); 17.0 until 2026-09-15, which was wrong) — __not__ a dual-row 2×7, whose rows are 2.54 mm apart. Standard height, __~2.50 mm standoff__, which is all that is needed: the expansion board sits __above__ the XIAO, not below it |
| __LiPo 500 mAh__ | One battery feeds both MCUs. __103 minutes from full__ at full load, timed on the bench — ~290 mA average ([#8](https://github.com/jwilleke/js-rocket-avionics/issues/8)). __Charged off the carrier__: the beacon out-draws the XIAO's charger |
| __Arming switch__ | Inline in the battery lead, zero pins. __Nothing bought and no part chosen__, so the 1.5 g is inherited from a superseded design and is the least trustworthy number on this page. Mechanism and status: [Arming-switch.md](../hardware/Arming-switch/Arming-switch.md) |
| __microSD__ | __Video and the log's slices, and in hand.__ The old A1/A2 / pSLC requirement was written when the sampler wrote to the card in flight; __PSRAM buffering removed that__. What is left is sequential video write — a speed-class question, not a random-IOPS one |

## Deliberately excluded

| Not used | Why |
|---|---|
| __Magnetometer__ | Motor and battery currents corrupt it, and gyro drift over 30 s is small |
| __Barometric static port__ | No legal location — the longest straight run above the sled is __0.33 caliber__ against the 1 cal a port needs. And nothing consumes the number: ejection is the motor delay, not a pyro channel |
| __MPU6050, LSM6DS3, ICM-20948, ICM-42688-P, ADXL345__ | All __±16 g__. All clip against 17.6 g. Cheap and unusable |
| __DFRobot Gravity 10DOF__ and similar integrated modules | Its BMI323 is ±16 g; also 32 × 27 mm, wider than the 24 mm carrier |
| __TeleMega__ | 31.75 mm will not enter the 40 mm bore with its battery. ~$400. Six pyro channels this rocket cannot use, and 70 cm telemetry needs an amateur licence |
| __LILYGO T-Beam__ | 33 mm wide × ~30 mm with the 18650 holder, against 22.6 mm of available depth at that width |
| __18650 cell__ | Would put nose mass near 65 g |
| __Second battery for isolation__ | +8 g the budget cannot afford — and not needed: 67 minutes on one battery at full camera load, down to ~3.5 V, reset neither board ([#8](https://github.com/jwilleke/js-rocket-avionics/issues/8)) |
| __Self-powered beeper__ | ~5 g, zero pins, and immune to MCU failure — but the buzzer already shares B's MCU. Revisit if recovery confidence outranks grams |

## Fallbacks worth remembering

- __IMU unobtainable__ → __BMI088__ (±24 g, ~$12, widely stocked) or split the job: __MPU6050 + ADXL375__. The split costs __+1 g and one I2C address, no extra pins__ — everything shares the bus.
- __Barometer unobtainable__ → any BMP3xx, or a generic __BMP280__. It is not the altimeter.

## Dimensions are not in this table

__Every part now has a weight, and this page owns those.__ It does not own a single dimension: __sizes, pin orders and which parts have actually been measured live in [module-pinouts.md](module-pinouts.md)__, which is also where the record of a board disagreeing with its datasheet belongs.

__Qwiic cables are bench-only.__ Both sensors ship with them, so breadboarding needs no soldering — but JST-SH is friction-fit and will shake loose under boost. The flight build solders to the 0.1 in header holes, so the cables are not in any weight above.

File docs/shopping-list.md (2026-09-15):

# Shopping list — avionics purchases

__What to buy and what it cost. Nothing else.__

__Part numbers and weights are in [BOM.md](BOM.md), which is the single source of truth for both.__ Do not restate either here — a number in two places is a number that will disagree with itself. What each part *is* and why it was chosen is there too.

__Costs on this page are from order confirmations, not estimates__ — except where a row says otherwise. Status is as of __2026-08-14__. __Every ordered part is now in hand.__

## Orders placed

| Order | Vendor | Date | Total | Status |
|---|---|---|---|---|
| __4000564800__ | Seeed | 2026-08-07 | __$35.65__ | __Delivered 2026-08-11.__ USPS `420430509261290198196828213362`, US warehouse |
| __4000564803__ | Seeed | 2026-08-07 | __$18.72__ | __Delivered 2026-08-13__, four days ahead of the earliest estimate. YanWen `UL400424782YP`, handed to USPS as `4204305014989219790323596301191013`. Left port 2026-08-09 09:05 |
| __3722796-7493495579__ | Adafruit | 2026-08-06 | __$50.11__ | __Delivered 2026-08-10__, a day early. UPS `1Z71EY050394397600` |
| | | | __$104.48__ | |

Both Seeed orders carry AIG insurance covering 100% of item value, __claimable within 7 days of the estimated delivery date__ — so check the boxes on arrival rather than when you get round to breadboarding.

## Bought

__Part numbers are in [BOM.md](BOM.md)__ — order from there, not from this page.

| Part | Vendor | Order | Cost | Status |
|---|---|---|---|---|
| __XIAO ESP32S3 & Wio-SX1262 Kit__ for Meshtastic & LoRa — __antennas included__ | Seeed | 4000564803 | __$10.90__ | __In hand 2026-08-13__ |
| __XIAO ESP32-S3 Sense__ — camera + microSD. __Listed as OV2640; the board that arrived carries an OV3660__ (2026-09-06) | Seeed | 4000564800 | __$13.99__ | __In hand 2026-08-11__ |
| __L76K GNSS Module for XIAO__ — active antenna included | Seeed | 4000564800 | __$11.99__ | __In hand 2026-08-11__ |
| __LSM6DSO32__ 6-DoF, ±32 g | Adafruit | 3722796 | __$12.50__ | __In hand 2026-08-10__ |
| __Piezo buzzer__ PS1240, passive | Adafruit | 3722796 | __$1.50__ | __In hand 2026-08-10__ |
| __LiPo 3.7 V 500 mAh__ | Adafruit | 3722796 | __$7.95__ | __In hand 2026-08-10__ |
| __BMP388__ barometer, STEMMA QT clone | [DIYmall](https://www.amazon.com/dp/B0GSYYT1K5) | — | ~$6–12 est. | __In hand.__ Measured 2026-08-08 |
| __microSD__ | already held | — | — | __In hand__ — several. See the note below on why the A1/A2 spec no longer binds |
| __Ground receiver__ — XIAO ESP32S3 & Wio-SX1262 Meshtastic node, cased, 2 dBi SMA antenna. Ground equipment, [#23](https://github.com/jwilleke/js-rocket-avionics/issues/23) | [Amazon](https://www.amazon.com/dp/B0GY4QC6GN) | — | — | __In hand 2026-09-13__ — arrived running LoRaHUB, reflashed to Meshtastic ([#23](https://github.com/jwilleke/js-rocket-avionics/issues/23)) |

Freight and tax are not in the rows above: Seeed shipping __$7.82**, Adafruit **UPS Ground $24.77 + $3.39 tax__.

> __The A1/A2 requirement was written for a design that no longer exists.__ It came from the era when the 500 Hz sampler wrote to the card *during flight*, where a 100–250 ms stall dropped samples. __PSRAM buffering removed that__: nothing touches the card until after landing. What remains is __sequential video write__, which is a speed-class question (Class 10 / U1 / V10), not the random-IOPS question A1/A2 answers. __Any reasonable card is very likely fine__ — check the class marking rather than buying.
>
> __Shipping cost more than the parts.__ $24.77 of freight against $21.95 of Adafruit goods. The project's ~$136 budget assumed nothing for it. Consolidate future orders.

__Every part is now on a receipt.__ Nothing on this page is inferred.

> __Seeed order 4000564800 was a blind spot for two days.__ Seeed never sent an invoice email for it — and that is the only mail carrying line items, so the order-received, tracking and insurance mails all showed a $35.65 charge against nothing. __The line items came off the account page, not the mail.__ If a Seeed order ever looks contents-free again, go straight to "My Orders" rather than searching the inbox harder.

Its two items are the __Sense ($13.99)** and the **L76K ($11.99)__ — $25.98 of goods against a $35.65 charge, so __$9.67 of shipping and insurance__.

__It landed well before the other Seeed box, as predicted.__ 4000564800 went USPS out of a __US warehouse__ and arrived __2026-08-11__; 4000564803 is YanWen out of China, left port 2026-08-09, 7–15 working days quoted at __2026-08-17 to 08-26__ — and it arrived __2026-08-13__, four days inside the earliest date. __Nothing ordered is outstanding.__

__Claim the AIG insurance window on both Seeed boxes now if at all__ — 7 days from the *estimated* delivery date, and 4000564803's estimate has not even started yet. Check the kit's contents against the listing (board, Wio-SX1262, both antennas) before that window is a question.

## Still to buy

| Part | Est. | Note |
|---|---|---|
| __Carrier PCB__ — 3 copies, 4-layer 1.6 mm, OSH Park, 24 × 115.7 mm | __~$43__ | __Blocked.__ Do not order before breadboarding — see below |
| __Pull-pin + subminiature microswitch__ | ~$5 | Arming, in the battery line. __Superseded the reed switch 2026-08-15__ — smallest hole, snap action, no printed mechanism. __Do not order yet__: no part chosen, and the sled can rotate, so where the pin enters is unresolved. See [the arming brainstorm](resources/2026-08-15-arming-and-access-brainstorm.md) and avionics #1/#2 |
| __MOSFET__, low-Vgs logic-level | ~$1 | __Only if__ the switch drives a gate rather than the load. Still open — a 3.5 mm jack's normalled contact is signal-rated even though its tip and sleeve are not. Adds a carrier footprint |
| M3 plastic machine screws, __M3 × 10__, ×2; Würth WA-SMSI M3 10 mm SMT standoffs (9774100360), ×2 | — | The carrier hangs off the web on the standoffs; screws from the web side. Longer than 10 mm pokes through the board's tall side ([PCB-carrier.md](../hardware/PCB-carrier/PCB-carrier.md)). The old "2×7 stacking headers, ~14 mm" line is gone: the kit's standard 7-pin headers are the flight part |
| Solder, flux, PET window, zip ties, standoffs | ~$15 | Consumables |

## The charging bench (#30) — ordered

__Ordered 2026-09-13 (operator).__ The MCP73831 is the last to land — its listing showed Sep 28–Oct 13 — and it is what the bench waits on.

__For [charging-bench.md](bench-work/charging-bench.md)__ — the carrier's charging circuit on a breadboard before it goes into copper ([#30](https://github.com/jwilleke/js-rocket-avionics/issues/30)). Part numbers are in [BOM.md](BOM.md); why each was chosen, in [PCB-carrier-design.md](../hardware/PCB-carrier/PCB-carrier-design.md#charging-on-the-carrier--q1-the-charge-isolation-fet-and-a-charger-chip--decided-not-yet-in-the-generator). __Prices, shipping and dates as the listings showed them on 2026-09-13, logged out__ — not receipts. __Read the shipping line on every listing before it goes in the cart__: the first pick for the chip, a $0.49 single, carried __$8.95 shipping each__ — $26.85 of freight on $1.47 of chips, and $26.85 of the $28.34 shipping charged at checkout; the other $1.49 was the 2.7 kΩ (operator, 2026-09-13).

| Part | Listing | Price | Shipping, date | Note |
|---|---|---|---|---|
| __AO3401A__ P-channel FET, SOT-23 — Q1 and Q2 | [100-pack](https://www.amazon.com/dp/B08RHFLH1K) | $6.95 | ships from Amazon, Sep 20–22 | Enough for the bench and every carrier |
| __MCP73831T-2ACI/OT__ charger, SOT-23-5 — U1 | [20-pack](https://www.amazon.com/dp/B0H332MZV5) | $7.50 | $1, Sep 28–Oct 13 | No Prime listing found. A marketplace chip can be a relabel — the bench's charge-current reading is the check |
| __SOT-23 to DIP adapters__, 6-pad | [20-pack](https://www.amazon.com/dp/B088M72B54) | $7.79 | free, Sep 23–28 | Fits SOT-23 and SOT-23-5. Header pins are not listed as included — any 2.54 mm male strip |
| __2.7 kΩ__, ¼ W, 1% | [100-pack](https://www.amazon.com/dp/B07DHH1DHF) | $9.09 | $1.49 | Sets U1's current, 370 mA |
| __100 kΩ__, ¼ W, 1% | [100-pack](https://www.amazon.com/dp/B07DHGY3VG) | $9.09 | $1.49 | The FETs' gate pull-down. __The bench does without it__: XIAO-ESP32S3-cam's own R9, 100 kΩ, already holds the gate low. The carrier gets one as a second |
| __4.7 µF__ ceramic, 50 V, 5.08 mm leads | [100-pack](https://www.amazon.com/dp/B0CN68WGZ6) | $9.24 | $1, Sep 22–Oct 1 | U1's two capacitors. __Skip if you have two__ of 4.7–10 µF |
| __JST-PH 2-pin pigtails__, male and female | [CHANZON, 30 pairs, 10 cm, 22 AWG](https://www.amazon.com/dp/B0B2DC8ST8) | — | __in hand__ (operator, 2026-09-13) | Battery and both XIAO pigtails onto the breadboard — the join harness has no place for the FETs. __Meter every one: [JST polarity is not fixed](../hardware/LiPo-500mAh/LiPo-500mAh.md#on-the-bench--the-join-harness)__ — the listing itself says not to trust the wire colour |

__All of it: $49.66 + $4.98 shipping. Without the 100 kΩ and the capacitors: $31.33 + $2.49.__ The carrier needs the same FETs and chip, from these packs, and its own small surface-mount resistors and capacitors; those go with the carrier order.

## What is actually blocking

__Nothing is on a truck any more.__ Every ordered part is on the bench as of __2026-08-13__. __Shipping has stopped being the blocker; bench work is.__ The copper order is now gated on the breadboard and on one caliper reading, both of which are available today.

### What can be done now, without waiting

1. __Breadboard XIAO-ESP32S3-cam in full.__ Sense, BMP388, LSM6DSO32, buzzer and battery are all here. Qwiic cables ship with both sensors, so the I2C bus needs no soldering. Confirm the camera, the microSD slot and both sensors enumerate, and that the strapping pins (GPIO3, 43, 44) behave.
2. __Measure and photograph every header__ before drawing a footprint — see [module-pinouts.md](module-pinouts.md). Only the BMP388 has been through this. __A wrong pin order scraps a board rather than costing a re-solder.__
3. __Measure and photograph the L76K's header.__ It mounts flat on the carrier as of 2026-09-09, so it takes a footprint like any other module and __its pin order has never been read__ — it did not need one while it rode the XIAO's pads. Grid photograph, outline and row order, same as the sensors.

### What the radio's arrival unblocks

1. __The L76K's own outline and pin order.__ The stack-clearance question this line used to carry is closed — the GPS goes flat on the carrier, so nothing has to share the XIAO stack. What the layout waits on now is the __footprint__: ~21 mm on a top face with 74 mm free, and a pin row nobody has read off the part.
2. __Board A bring-up__ — it should enumerate as a Meshtastic device untouched, with no firmware written.
3. __Then__ place, route, and order copper.

__Nothing above is gated on a parcel any more.__ The whole sequence is bench time.

__A layout error costs ~$33 and two weeks. A wiring error costs minutes.__ That is the whole reason for this sequence.

__Board B's firmware does not exist yet__ and is not on any critical path above — but it is what turns a breadboard into a flight recorder, and nothing has been written.

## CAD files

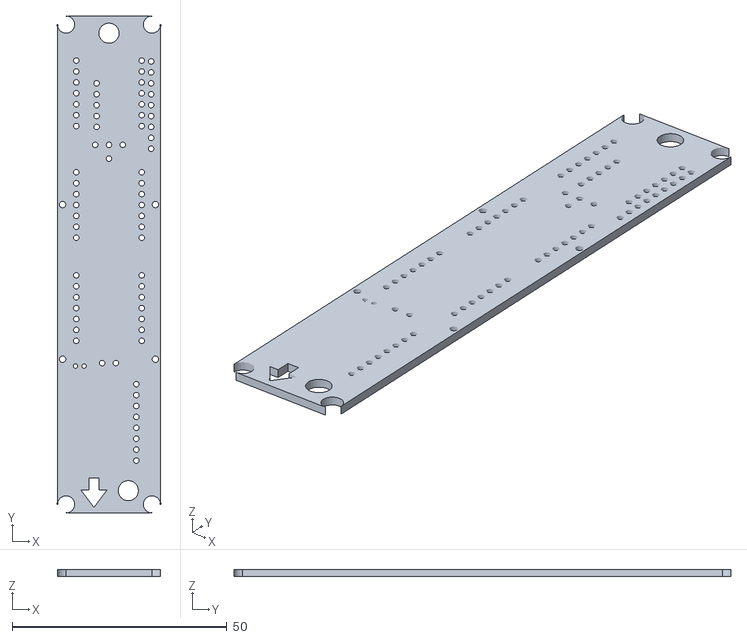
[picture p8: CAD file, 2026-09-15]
hardware/PCB-carrier/fit-mock/PCB-carrier-fit-mock.stl
24.0 x 115.7 x 1.60

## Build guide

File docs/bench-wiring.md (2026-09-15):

---
title: Bench wiring
description: What plugs into what on the breadboard, in plain words, before any test procedure.
---

# Bench wiring

__This page is the first one.__ [bench-bringup.md](bench-bringup.md) says what to run and in what order; it assumes the thing is already wired. This says how to wire it, physically, on a breadboard, with nothing taken as known.

## The words this project keeps using

| Word used here | What it actually is |
|---|---|
| __battery__ | [LiPo-500mAh](../hardware/LiPo-500mAh/LiPo-500mAh.md) — one LiPo pouch, 500 mAh, 3.7 V, 29 × 36 × 4.75 mm, a red and a black wire ending in a small white 2-pin plug. __One battery, feeding both boards__, rather than one each. Older commits and GitHub issues call this "the cell"; it is the same object and the word has been dropped |
| __rail__ | One of the long red/blue strips down the edge of a breadboard. Every hole in a rail is connected to every other hole in that rail. Used so ten things can share one supply wire |
| __pigtail__ | A short wire soldered directly to a board, ending free, because there is no connector to plug into |
| __castellated pads__ | The 14 half-holes along a XIAO's two long edges. Header pins solder into these. This is the only edge you can reach with jumper wires |
| __B2B__ | Board-to-board. A flat connector where one board plugs onto another with no wires — how the camera board and the radio board mate to their XIAOs. Nothing to wire |
| __Qwiic / STEMMA QT__ | A 4-wire snap-in plug (power, ground, and the two I2C wires) on the small sensor boards. Convenient __only if the other end of the cable has bare pins__ — a XIAO has no Qwiic socket |
| __I2C__ | A 2-wire bus: `SDA` (data) and `SCL` (clock). Both sensors share both wires. That is normal and correct |
| __passive piezo__ | The buzzer. A bare disc with no electronics in it. The pin drives it directly, and __it has no supply wire__ — just signal and ground |
| __LDO__ | __Low-DropOut regulator.__ The chip that turns a higher, moving voltage into a steady lower one — on a XIAO, the battery's 4.2 V charged down to ~3.0 V flat becomes a steady __3.3 V__ on the `3V3` pin. It is __linear__, so it burns the difference as heat rather than converting it: (V in − V out) × current, which is ~__0.27 W__ at 300 mA in a sealed cone. Two facts follow that this project keeps running into — __two LDOs on one wire do not share the load__ (whichever targets the marginally higher voltage supplies everything until it sags to meet the other), and __an LDO's output is not an input__, which is why power goes to a sensor's `VIN` and never its `3Vo` |
| __brownout__ | The supply voltage sagging low enough that the chip resets itself. The thing [#8](https://github.com/jwilleke/js-rocket-avionics/issues/8) exists to catch |
| __3V3 / 5V__ | Two supply pins on the XIAO. __Use 3V3 for everything here.__ On battery power the 5V pin is dead — it only has voltage when USB is plugged in |

## What you are building

Two module stacks and a breadboard. The stacks are already assembled by their B2B connectors and need no wiring between their own layers.

```text
  STACK 1 -- the recorder                    STACK 2 -- the beacon
  XIAO-ESP32S3-cam                           XIAO-ESP32S3-lora
    + Sense camera board (camera, microSD)     + Wio-SX1262 radio
                                               L76K GPS beside it, on its board
  Runs our firmware. Everything on the        Runs stock Meshtastic, untouched.
  cam board hangs off this one.               Four wires to the L76K, then power.
                \                            /
                 \                          /
                  ------- ONE BATTERY -------
```

__Only stack 1 gets sensors and a buzzer.__ Stack 2 gets the GPS and nothing else.

__The [Wio-SX1262](../hardware/Wio-SX1262-LoRa/Wio-SX1262-LoRa.md) needs no wiring__: it is on its B2B connector, so once it is mated there is nothing left to push into a board. The [L76K-GNSS](../hardware/L76K-GNSS/L76K-GNSS.md) is no longer in that stack at all. It mounts __flat on the carrier__ (2026-09-09), so on the bench it sits on the lora board and takes four jumpers — [The lora board](#the-lora-board), below.

### As actually set up: two boards, one XIAO each

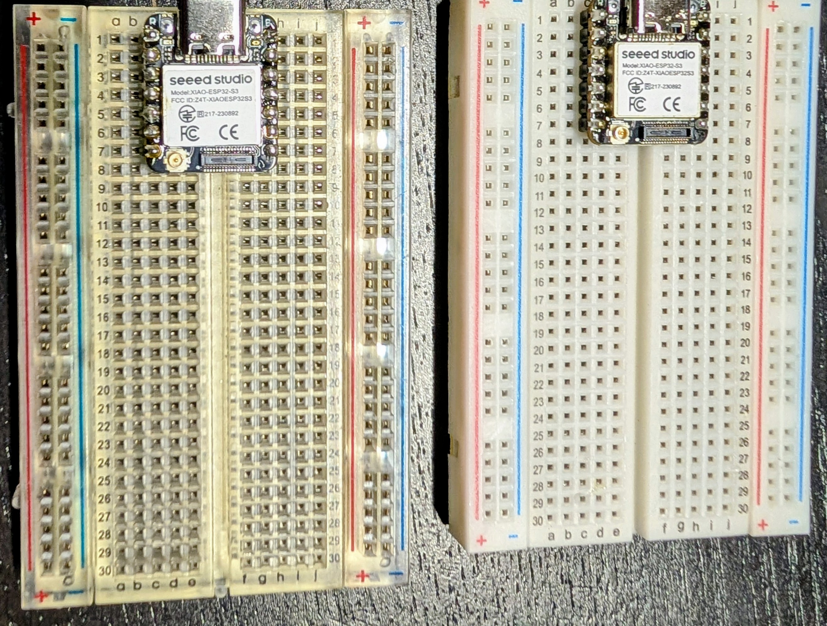
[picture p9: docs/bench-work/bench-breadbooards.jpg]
Two 30-row breadboards, one bare XIAO ESP32-S3 seated across the centre channel on each, no other parts fitted


__Each XIAO is on its own 30-row A–J board__, seated across the centre channel, and neither has its expansion board mated yet. That is a better arrangement than the single board this page first assumed, and nothing in the wiring below has to change for it — because __stack 2 was never going to share a rail with stack 1__. The two boards meet only at the battery, by soldered pigtails to underside pads, not breadboard holes.

Two consequences worth stating, because "rail" now means two different things:

- __Each board's rails carry its own XIAO's 3V3.__ The cam board's feed the sensors; the lora board's feed only the L76K. Do not run a jumper between the two boards' rails: the only intended path between the stacks is the battery junction, and a second one turns a measurement into a guess when [#8](https://github.com/jwilleke/js-rocket-avionics/issues/8) looks for sag
- __The grounds are common through the battery junction.__ That is what makes a shared-battery brownout measurable at all. __With the battery connected, USB goes into one board only, never both__ — two chargers on one battery is the case [LiPo-500mAh.md](../hardware/LiPo-500mAh/LiPo-500mAh.md#two-chargers-on-one-battery) rules out

__Both XIAOs are bare in the photograph__, which is the moment to check item 3 below: the `BAT` pads are reachable now and will not be once the expansion boards go on.

## Check three things on the parts before wiring anything

__1 — The cam copy has no headers soldered on.__ [XIAO-ESP32S3-cam](../hardware/XIAO-ESP32S3-cam/XIAO-ESP32S3-cam.md) ships its two 7-pin strips loose; [the lora copy](../hardware/XIAO-ESP32S3-lora/XIAO-ESP32S3-lora.md) already has its soldered. No headers means nothing to push into a breadboard, so those two strips have to go on first — pins pointing __down__, because the Sense camera board sits on top.

__2 — Test-fit the header strips in the breadboard before you solder them.__ The XIAO's header pins sit __15.24 mm apart__, six pitches ([Seeed's footprint](../hardware/XIAO-ESP32S3-cam/PCB_Design_XIAO4.png), [#33](https://github.com/jwilleke/js-rocket-avionics/issues/33)), so the strips straddle the centre channel on any pair six pitches apart. Count in millimetres, not in holes: the channel is 7.62 mm wide, three pitches, so letters mislead.

```text
a 0.00   b 2.54   c 5.08   d 7.62   e 10.16  | channel |  f 17.78  g 20.32  h 22.86  i 25.40  j 27.94
```

__`c` and `g`__ are 15.24 mm apart, as are `d`/`h` and `e`/`i`.

> __Corrected 2026-09-15.__ This step used to say the rows were 17.0 mm apart and that seven pitches (17.78 mm, `c`/`h`) was the fit. The 17.0 was the centre of KiCad's SMD pads, not the pins, and the 17.78 was worked from it, not measured. It asked for a caliper check that was never made, and the same wrong figure went into the carrier ([#33](https://github.com/jwilleke/js-rocket-avionics/issues/33)). If a XIAO in the photograph below sits seven pitches wide, its strips are not in its holes.

__3 — Solder the BAT pigtails with the XIAO out of the breadboard.__ `BAT+`/`BAT−` are pads on the __back face__, inboard of the `D3`/`D4` edge, and the back face is whatever the XIAO is standing on — the breadboard now, the carrier later at 2.50 mm. __The expansion board is not the obstruction__: its B2B is on the *front*, so it can go on and come off with the pigtails already fitted. Faces and evidence are in [XIAO-ESP32S3-cam.md](../hardware/XIAO-ESP32S3-cam/XIAO-ESP32S3-cam.md#which-face-carries-what--settled-off-seeeds-two-drawings-and-the-stack-itself). __Lift the module, solder, seat it again__ — do not try to work under a seated one.

> __The battery reaches a XIAO only by soldered wire.__ There is no battery connector on these modules. This is the one soldering job the bench build cannot avoid, and [BOM.md](BOM.md)'s "the bench build needs no soldering" is true only of the I2C sensors, which have plug-in cables.

## The breadboard

Breadboard layout: XIAO-ESP32S3-cam straddling the centre channel, both sensors and the piezo wired to it, and the battery soldered to the underside BAT pads of both modules

__Regenerate it with `python3 hardware/scripts/gen_breadboard_svg.py`__ — the placement is data in that script, so a corrected pin order is one edit and a redraw rather than a hand-patched picture that disagrees with the table below.

### Build it in this order

Each step is testable before the next one can hide its mistake.

1. __Headers on the cam copy first__, dry-fitted in the breadboard as above, then soldered. Nothing else can start until the module can sit in the board.
2. __Solder the battery pigtails to both modules' `BAT+`/`BAT−` pads__ while the pads are still reachable — before the expansion board goes back on. Do not connect the battery yet.
3. __Push the XIAO in across the centre channel__, USB-C to the left. Seven columns; the module bridges the gap so its two rows are on separate nodes.
4. __Two jumpers to the rails:__ `3V3` (pin 12) to the red rail, `GND` (pin 13) to the blue. Anywhere in the same column works — a column of five holes is one connection.
5. __Power the board over USB alone__ and confirm it enumerates. Stop here if it does not.
6. __Sensors in, then their power__, then the two bus wires from `D4` and `D5`. Run [`bringup-cam`](../firmware/bringup-cam/): the I2C scan either finds `0x77` and `0x6A` or it does not. __Count the pins from the USB-C end — `D4` is the fifth, `D5` the sixth.__ The first build landed both wires one pin short, on D3/D4 (2026-09-12). If the scan finds nothing while both sensors' power LEDs are lit, run [`i2c-find`](../firmware/i2c-find/): it names the pins the wires are actually on.
7. __Buzzer last of the signal wiring__, one leg to `D0`, one to ground.
8. __The battery last of all__, and only once everything above passes on USB.

### The XIAO's pins, as text

The drawing and this agree; the text version is here because a pin order is worth being able to grep. Viewed __from above with the USB-C at the left__:

```text
   top edge, left to right     5V   GND  3V3  D10  D9  D8  D7
   bottom edge, left to right  D0   D1   D2   D3   D4  D5  D6
```

__That is a mirror of [module-pinouts.md](module-pinouts.md#xiao-esp32s3--read-off-the-underside-2026-09-08)__, which reads the part from the underside with the USB-C at the top. Both describe the same 14 pads. The consequence for wiring is that __`D4`/`D5` are in the lower half of the board and `3V3`/`GND` are in the upper__, which is why the bus wires cross the channel and the power wires do not.

### Every connection, as a list

__Every rail named here is on the *cam* board__ — see the two-board note above. The lora board has its own table, [below](#the-lora-board).

| From | To | Note |
|---|---|---|
| Battery red (+) | `BAT+` pad, __cam__ XIAO underside | soldered pigtail |
| Battery red (+) | `BAT+` pad, __lora__ XIAO underside | soldered pigtail, same wire junction |
| Battery black (−) | `BAT−` pad, both XIAOs | soldered pigtails |
| cam pin 12 `3V3` | cam board red rail | the only thing feeding it — __never `5V`__, which is dead on battery |
| cam pin 13 `GND` | cam board blue rail | |
| cam red rail | BMP388 `VIN` | __not `3Vo`__ — that pin is the sensor's own regulator output and back-feeding it kills the part |
| cam blue rail | BMP388 `GND` | |
| cam pin 5 `D4` | BMP388 `SDA` | |
| cam pin 6 `D5` | BMP388 `SCL` | |
| cam red rail | LSM6DSO32 `VIN` | Primary row, __not__ the 5-pin Aux row |
| cam blue rail | LSM6DSO32 `GND` | |
| cam pin 5 `D4` | LSM6DSO32 `SDA` | same wire as the BMP388's — two sensors, one bus |
| cam pin 6 `D5` | LSM6DSO32 `SCL` | same wire as the BMP388's |
| cam pin 1 `D0` | buzzer, either leg | |
| cam blue rail | buzzer, other leg | |
| — | __XIAO-ESP32S3-lora__ | nothing on this board. Its own board is [below](#the-lora-board) |
| — | BMP388 `CS`, `SDO`, `3Vo`, `INT` | left alone. `CS` is [#19](https://github.com/jwilleke/js-rocket-avionics/issues/19) — if the part does not answer at `0x77`, that pin is the first suspect |
| — | LSM6DSO32 `DO`, `CS`, `I1`, `I2`, and the whole 5-pin Aux row | left alone. No interrupt line exists in this design; the FIFO is read by polling |

__It fits on 30 rows, with the XIAO across the channel at the top:__

```text
rows  1..7    XIAO-ESP32S3-cam, pads in c and h
rows  9..16   BMP388, 8-pin row
rows 18..26   LSM6DSO32, 9-pin Primary row
rows 28..29   buzzer
```

A sensor on one header row stands on that row alone and will tilt — that is cosmetic, not electrical. If the Qwiic cables have loose pins on one end, the sensors need not go into the board at all.

### The sensor cables, which may or may not save you the soldering

Both sensors have a Qwiic socket on each short edge __and__ a row of header holes. Which one you use depends on what the supplied cables end in, and that is worth checking before the session rather than during it:

- __Qwiic plug on one end, four loose pins on the other__ — plug into the sensor, push the pins into the breadboard, done. No soldering
- __Qwiic plugs on both ends__ — these only join one sensor to another. There is no Qwiic socket on a XIAO, so the bus still has to reach the breadboard through the header holes, and the __BMP388's header ships loose and unsoldered__

Either way the four wires are the same four: `VIN`, `GND`, `SDA`, `SCL`. On a Qwiic cable they are conventionally red, black, blue (SDA) and yellow (SCL) — __confirm against the sensor's own silkscreen rather than trusting the colours__.

## The lora board

The second 30-row breadboard: XIAO-ESP32S3-lora across the channel at the left, the L76K across the channel beside it with its antenna end facing the XIAO, four jumpers for 3V3, GND, D6 and D7, and the battery soldered to the XIAO's underside BAT pads

__Regenerate it with `python3 hardware/scripts/gen_breadboard_lora_svg.py`.__ The L76K's pinout comes from [L76K-GNSS.md](../hardware/L76K-GNSS/L76K-GNSS.md#pinout--from-seeeds-schematic-not-the-listing), which owns it.

| From | To | Note |
|---|---|---|
| lora pin 12 `3V3` | lora board red rail | the L76K's only supply |
| lora pin 13 `GND` | lora board blue rail | |
| lora red rail | L76K `3V3` | __not `5V`__: it connects to nothing on the module, and is dead on battery anyway |
| lora blue rail | L76K `GND` | |
| lora pin 7 `D6` | L76K __`RX`__ | the XIAO transmits on `D6`. The carrier calls this net `GPS_TX` |
| lora pin 8 `D7` | L76K __`TX`__ | the XIAO listens on `D7`. The carrier calls this net `GPS_RX` |
| — | L76K `5V`, `RESET`, `WAKE`, everything else | left alone. `RESET` and `WAKE` are pulled up on the module |
| — | GPS patch | on its U.FL lead, off the board, facing up |

__Two traps, both on the drawing:__

- __The L76K is not the XIAO's twin.__ Its pads are the XIAO's pattern, but component side up they are mirrored against the XIAO beside it. Seat it from the drawing, not by copying the XIAO
- __Wire by position, not by the silkscreen word.__ TX to TX is the mistake, and it fails silently: the GPS just never talks

__Stock Meshtastic reads the GPS on `D6`/`D7` — confirmed on the bench, 2026-09-11.__ Its startup log says `Use GPIO44 for GPS RX` (D7), `Use GPIO43 for GPS TX` (D6), then `L76K detected`, which needs both wires: it asks on D6 and the module answers on D7. No pin setting is needed. The log and the rest of the reading are on [#6](https://github.com/jwilleke/js-rocket-avionics/issues/6#issuecomment-5639176943). If a later build ever reports no GPS with the four jumpers in, suspect the wiring before the firmware.

## Rules for handling the battery

Read these once. They are the only part of this page that can hurt you or destroy a part.

- __Do not let the two battery wires touch each other.__ A LiPo has no fuse and will happily deliver tens of amps into a short, hot enough to set the pouch on fire. Cut and strip __one wire at a time__, and insulate each before starting the other
- __Red to `BAT+`, black to `BAT−`. Reversed destroys the XIAO instantly__ — [XIAO-ESP32S3-cam.md](../hardware/XIAO-ESP32S3-cam/XIAO-ESP32S3-cam.md) records this, and it is why the carrier will silkscreen the polarity
- __Charge through one USB port at a time.__ Both XIAOs have their own charger and both sit on the same battery; two chargers on one battery will argue
- __USB powers the board.__ Anything plugged into USB is running off the computer, not the battery. A test of the battery with a USB cable attached is a test of the computer
- __Do not discharge the battery below about 3.0 V__, and stop the test there rather than running it flat. A LiPo taken deeply flat may not come back

## The one thing worth doing twice

The carrier PCB ties __both XIAOs' `3V3` pins to the same plane__, so on the finished board the two regulators run in parallel — [PCB-carrier.md](../hardware/PCB-carrier/PCB-carrier.md#two-regulators-on-one-net-which-nobody-chose-deliberately) records that as a consequence of the layout rather than a decision anyone made.

The bench does not have to reproduce that on the first run, and should not:

1. __First, battery only.__ Battery to both boards' BAT pads, `3V3` rails kept separate — the wiring above. Any disturbance the beacon shows now travelled through __the battery__, which is exactly the coupling [#8](https://github.com/jwilleke/js-rocket-avionics/issues/8) is about
2. __Then, if you want the carrier's own case__, add one wire joining the two `3V3` pins and repeat. Different question, different failure, and __a bad result here is cheap to fix in copper and expensive to fix after ordering__

Two runs, one wire apart. Write down which one each set of numbers came from.

## Optional: letting the firmware see the battery voltage

[`soak-power`](../firmware/soak-power/) catches every reset without this. The divider only adds the __shape of the sag__ — what the voltage did on the way down.

```text
   BAT+ ----[ 100k ]----+----[ 100k ]---- GND
                        |
                        +---- D1  (pin 2 on the cam XIAO)
```

Two ordinary 100k resistors. The junction between them sits at half the battery voltage, which is what keeps it inside the pin's safe range — __do not connect `BAT+` to a pin directly__, 4.2 V will damage it. Then build with `-DSOAK_VBAT_PIN=2 -DSOAK_VBAT_DIVIDER=2.0f`; the flags are documented in [`platformio.ini`](../firmware/soak-power/platformio.ini).

## Then, and only then

Once this is wired and a XIAO enumerates over USB, [bench-bringup.md](bench-bringup.md) has the run order — stack check, beacon, recorder, both on one battery. Nothing there works before this page does.

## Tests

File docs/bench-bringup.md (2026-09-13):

---
title: Bench bring-up
description: One session that closes #6, #7 and #8 — the epic that gates ordering copper.
---

# Bench bring-up

__Wire it first.__ This page is the run order and it assumes the bench is already built. What plugs into what, in plain words and with the battery handling spelled out, is [bench-wiring.md](bench-wiring.md) — start there. "The battery" throughout this page means __the one LiPo battery__ feeding both boards.

__One session, three issues.__ [#6](https://github.com/jwilleke/js-rocket-avionics/issues/6), [#7](https://github.com/jwilleke/js-rocket-avionics/issues/7) and [#8](https://github.com/jwilleke/js-rocket-avionics/issues/8) all block [#4](https://github.com/jwilleke/js-rocket-avionics/issues/4), which blocks [#11](https://github.com/jwilleke/js-rocket-avionics/issues/11), which is the order. They are written as three issues because they fail differently; they are __one bench session__ because the setup is the same and #8 cannot run until the other two have.

__Nothing needs buying.__ Every part is in hand. The carrier PCB and the arming switch are not needed to power anything up — and the arming switch is now [a convenience rather than a requirement](../hardware/Arming-switch/Arming-switch.md), so it is not waiting on this either.

__Nothing in `fab/` goes to a fab until this closes.__ That directory holds a complete-looking gerber set generated from a board that is missing most of its footprints.

## Run it in this order, and the order is the point

Each step is cheap to fail and tells you something the next one assumes. Running #8 first would tell you nothing, because a brownout you cannot attribute is not a measurement.

| | Step | Fails cheaply because |
|---|---|---|
| 1 | __Stack check__, no power | A mechanical collision is not a bench nuisance, it is a design change |
| 2 | [__#6__](https://github.com/jwilleke/js-rocket-avionics/issues/6) XIAO-ESP32S3-lora alone | No firmware to write. If it does not enumerate, nothing downstream matters |
| 3 | [__#7__](https://github.com/jwilleke/js-rocket-avionics/issues/7) XIAO-ESP32S3-cam alone | Sensors before camera; I2C before SD. Each layer rules out the one below |
| 4 | [__#8__](https://github.com/jwilleke/js-rocket-avionics/issues/8) both on one battery | Only meaningful once each half is known good |

## 1 — Stack check, before any power

__[#6](https://github.com/jwilleke/js-rocket-avionics/issues/6)'s mechanical question is closed, and not by a measurement.__ It asked whether the [L76K](../hardware/L76K-GNSS/L76K-GNSS.md) and the [Wio-SX1262](../hardware/Wio-SX1262-LoRa/Wio-SX1262-LoRa.md) could share the space above one XIAO-ESP32S3-x — never tested, the parcels having arrived weeks apart. __The L76K now mounts flat on the carrier__ (2026-09-09), so nothing has to clear anything and there is no dry-stack gate before soldering. What remains on #6 is electrical: does the radio beacon, does the GPS get a fix, and does the L76K's active antenna desense the receiver.

- Fit [XIAO-ESP32S3-lora](../hardware/XIAO-ESP32S3-lora/XIAO-ESP32S3-lora.md) + Wio-SX1262 + L76K, dry, no battery
- __If they foul, stop and write it down.__ That is a layout change: the L76K returns to the carrier as a footprint needing ~21 mm, which the 95 mm board has but [#14](https://github.com/jwilleke/js-rocket-avionics/issues/14) has not allowed for
- Check the __≥50 mm antenna separation__ from [design.md](design.md) is physically achievable in the stack you just built. 915 MHz TX desenses a 1575 MHz front end by broadband noise, and the bench is where that first becomes observable

## 2 — #6, the beacon

__No firmware.__ That is the entire premise of this module: a supported Meshtastic device out of the box. Bring-up here confirms the premise rather than writing code.

__Step by step, from the wired breadboard to a GPS fix: [lora-bench-board.md](bench-work/lora-bench-board.md).__

- Power the matched kit over USB and confirm it __enumerates as Meshtastic, untouched__
- Get a __GPS fix outdoors__ and record __time to first fix__
- Range-check the __82 mm U.FL whip__. The beacon is the recovery system, and an untested link is an untested recovery

> __Its USB-C is not used in the flight build__ — charging and service go through the Sense stack, because this module carries stock Meshtastic and nothing else ([the firmware rule](../hardware/XIAO-ESP32S3-lora/XIAO-ESP32S3-lora.md#firmware--stock-meshtastic-only-updated-on-purpose-frozen-for-flight)). Using its port on the bench is fine and expected; just note that the flight configuration has no service access to it.

## 3 — #7, the recorder

__Firmware exists now:__ [`firmware/bringup-cam/`](../firmware/bringup-cam/), a PlatformIO project. It runs #7's four criteria in the order that fails cheapest and prints a PASS/FAIL line for each. __It is untested — no hardware has run it__ — so a failure means check the wiring *and* check the code.

```sh
cd firmware/bringup-cam
pio run -t upload && pio device monitor
```

__No IDE settings to remember.__ Board, PSRAM and the partition table are all in [`platformio.ini`](../firmware/bringup-cam/platformio.ini), which is why this is not a sketch — `-DBOARD_HAS_PSRAM` is load-bearing, and a camera that fails to allocate its frame buffers reports an error that reads like a hardware fault.

Four wires per sensor, both on I2C:

```text
XIAO 3V3 -> sensor VIN      <- NOT 3Vo, that is the sensor's own regulator output
XIAO GND -> sensor GND
XIAO D4  -> sensor SDA
XIAO D5  -> sensor SCL
buzzer   -> D0 and GND      <- passive piezo, no supply rail
```

__Three traps, already paid for once__ and recorded in [module-pinouts.md](module-pinouts.md):

- __CS must be HIGH__ or a BMP3xx drops into SPI mode and never answers on I2C. If 0x77 is silent, check this before anything else
- __SDO selects the address, it is not data.__ High = 0x77, low = 0x76
- __Ignore the seller's wiring diagram.__ It is SPI, wired to Arduino 13/12/11/10, and following it wastes a session

__One trap that is new and not in any issue:__ the LSM6DSO32's full-scale bits are __not__ the LSM6DSO's. On the -32 part, `FS = 01` is ±32 g and `11` is ±16 — so assuming the top code is the top range gives you half the range and a plausible-looking number. If every axis reads near zero at rest, that is the first thing to check.

## 4 — #8, both on one battery

__This is the one that can change the copper__, so run it last and run it properly.

- Both modules powered from __the one battery at the same time__ — not one each, and not off USB — with the camera capturing and the LoRa transmitting. Wiring: [bench-wiring.md](bench-wiring.md)
- Scope the rail through __camera inrush and SD write bursts__; failing a scope, watch the beacon for resets and read its log
- Measure __actual current draw__ against the ~300 mA estimate
- __Repeat on a partially discharged battery.__ A full battery is the easy case and sag is worst near the bottom

__The load and the record are firmware now:__ [`firmware/soak-power/`](../firmware/soak-power/), a PlatformIO project. It drives the worst case the flight build can produce — capture, then an SD write burst, as fast as the card takes it — and appends __one CSV line per cycle__ to `/soak-power.csv`, plus a line per boot carrying `esp_reset_reason()`. __It is untested — no hardware has run it.__

```sh
cd firmware/soak-power
pio run -t upload          # then UNPLUG the USB and run from the battery
```

- __USB-C powers the board.__ A run with the monitor attached measures the bench supply and says nothing about the battery. Flash, unplug, run, then read the card
- __A brownout names itself.__ The ESP32-S3's own detector fires before the CPU misbehaves, so `BROWNOUT` in the reset column is the observation this issue is missing — and a `PANIC` in that column is a bug in the firmware rather than evidence about the battery, which is why every reason is logged and not just the interesting one
- __The log is on the card because the event is a reset.__ Each line is opened, written and closed, so a run loses at most one line to the thing it is measuring
- __Endurance falls out of the same file.__ Count boot lines, read the last uptime before each; no separate test and no trust in the ~300 mA estimate
- __The voltage columns are optional and worth the two resistors.__ The XIAO has no battery divider — BAT+/BAT− are bare pads — so without one the reset is caught and attributed but the shape of the sag is missing. Two 100k from BAT+ to D1 (GPIO2) fills in `vbat/vmin/vmax`, sampled by a task on the other core so a blocking SD write cannot hide its own dip. Wiring and build flags are in [`platformio.ini`](../firmware/soak-power/platformio.ini)
- __This does not replace the scope__, it replaces having nothing when there is no scope — and it logs for an hour, which a trace does not

__XIAO-ESP32S3-lora is the other half of the test and takes no firmware__: it runs stock Meshtastic, and what is being watched is whether it reboots. Read its own log after the run and line its reboots up against the CSV's write bursts.

### Measure two more things while it is on the bench

Neither is in #8 as written, and both are nearly free once the setup exists.

__Actual runtime.__ 500 mAh against a ~300 mA *estimate* gives ~100 minutes. That figure now carries weight it did not before: with arming settled as a convenience, __"how long from connecting the battery to recovery"__ is the real operational limit on a launch day. Measure the draw rather than trusting the estimate, and correct [BOM.md](BOM.md).

__The two regulators.__ Both modules' `3V3` pins land on the __same plane__ on the carrier, so their regulators run __in parallel__ — see [PCB-carrier.md](../hardware/PCB-carrier/PCB-carrier.md#how-power-actually-reaches-everything). Linear regulators do not share load: whichever holds the marginally higher output does all the work until it current-limits, and if one module loses its pigtail the other back-feeds into its regulator output. __This is a consequence of the layout rather than a decision anyone made.__ Put a meter on both 3V3 pins with the camera running and write down what you see. The regulator type is assumed rather than read off Seeed's schematic, so read that too if the numbers look odd.

## What closing this epic requires

Not "it worked". A __stated verdict__ on the coupling, because that is the one that lands in copper:

- __acceptable__ — order as drawn
- __needs decoupling__ — bulk capacitance or separate regulators, and it goes into the layout __before__ [#16](https://github.com/jwilleke/js-rocket-avionics/issues/16)
- __needs the second cell__ — which was priced and rejected at +8 g, and can only be re-priced now that somebody knows how bad the coupling actually is

Write the numbers down even when they are boring. The predictions this epic exists to test have been sitting in [BOM.md](BOM.md) as accepted risks for weeks, and an accepted risk nobody measured is just a guess with a checkbox.

## After this epic — the charging bench

__[#30](https://github.com/jwilleke/js-rocket-avionics/issues/30) also blocks the order__, and has its own bench session: the carrier's charging circuit — Q1, Q2 and the charger chip — on a breadboard with both XIAOs and the battery. It needs parts bought first. Procedure: [charging-bench.md](bench-work/charging-bench.md).

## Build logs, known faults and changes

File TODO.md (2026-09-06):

---
title: TODO
description: Pointer to the combined backlog, which is ranked in js-rocket.
last_updated: "2026-09-06"
---

# TODO

__This repo's backlog is ranked in [js-rocket's `TODO.md`](https://github.com/jwilleke/js-rocket/blob/main/TODO.md), not here.__

Issues from this repository appear there prefixed __`aelc-#N`__, interleaved into the same priority bands as the airframe's. Unprefixed numbers are js-rocket.

## Why one file and not two

__Flight 3's camera runs through both repositories.__ The Nosecone port is cut in js-rocket ([#88](https://github.com/jwilleke/js-rocket/issues/88)) and the sled shelf that decides its size is there too ([#89](https://github.com/jwilleke/js-rocket/issues/89)) — but the lens standoff that dimensions both is measured here ([#9](https://github.com/jwilleke/js-rocket-avionics/issues/9)), behind the header height ([#10](https://github.com/jwilleke/js-rocket-avionics/issues/10)). __A backlog showing only half of that hides the critical path.__

Two files ranking the same work drift apart, and the drift is silent. So this one holds no bands.

## The relationships are on GitHub, not in a list here

Both epics in this repo are __sub-issues of the flight-3 epic__, [js-rocket#63](https://github.com/jwilleke/js-rocket/issues/63), and each owns its own children:

- [#4](https://github.com/jwilleke/js-rocket-avionics/issues/4) — __[EPIC] Power the avionics on the bench__, parent of [#5](https://github.com/jwilleke/js-rocket-avionics/issues/5) [#6](https://github.com/jwilleke/js-rocket-avionics/issues/6) [#7](https://github.com/jwilleke/js-rocket-avionics/issues/7) [#8](https://github.com/jwilleke/js-rocket-avionics/issues/8) [#9](https://github.com/jwilleke/js-rocket-avionics/issues/9) [#10](https://github.com/jwilleke/js-rocket-avionics/issues/10)
- [#11](https://github.com/jwilleke/js-rocket-avionics/issues/11) — __[EPIC] Everything needed before the carrier PCB is ordered__, parent of [#1](https://github.com/jwilleke/js-rocket-avionics/issues/1) [#2](https://github.com/jwilleke/js-rocket-avionics/issues/2) [#12](https://github.com/jwilleke/js-rocket-avionics/issues/12) [#13](https://github.com/jwilleke/js-rocket-avionics/issues/13) [#14](https://github.com/jwilleke/js-rocket-avionics/issues/14) [#15](https://github.com/jwilleke/js-rocket-avionics/issues/15) [#16](https://github.com/jwilleke/js-rocket-avionics/issues/16)

__#4 gates #11.__ Nothing is ordered until the bench has run.

Session history for this repo stays in `private/project_log.md`.

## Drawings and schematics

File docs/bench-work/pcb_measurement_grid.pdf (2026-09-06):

# PCB measurement grid — 1 mm

US Letter (215.9 × 279.4 mm) · Print at 100% / Actual size · Do NOT use Fit to page or Shrink to fit

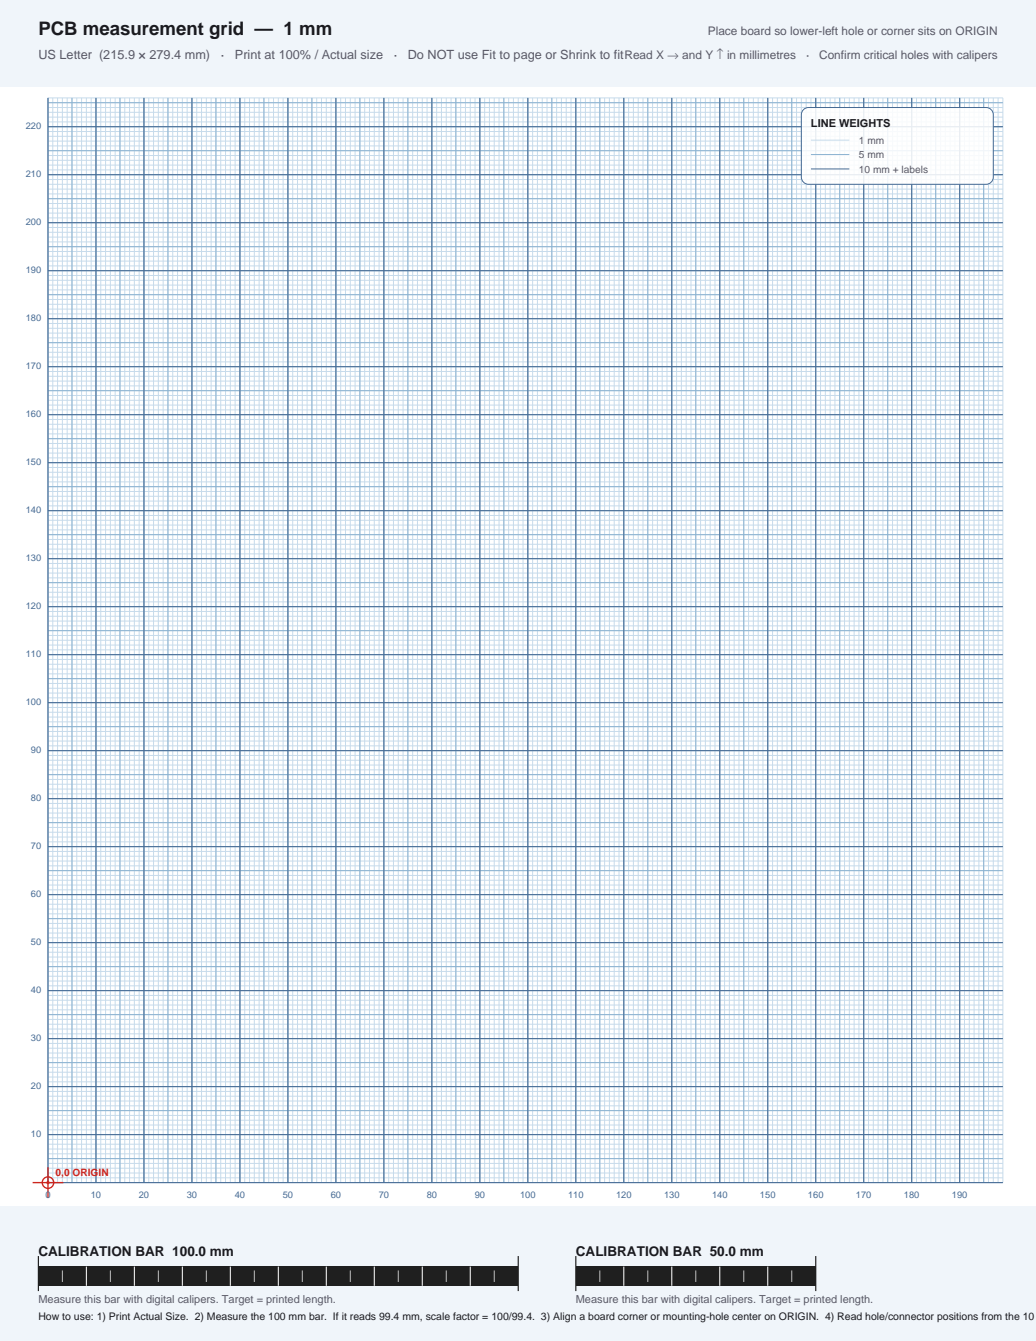
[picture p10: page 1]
0,0 ORIGIN; LINE WEIGHTS; 1 mm 5 mm 10 mm + labels

Place board so lower-left hole or corner sits on ORIGIN

Read X → and Y ↑ in millimetres · Confirm critical holes with calipers

CALIBRATION BAR 100.0 mm

CALIBRATION BAR 50.0 mm

Measure this bar with digital calipers. Target = printed length.
How to use: 1) Print Actual Size. 2) Measure the 100 mm bar. If it reads 99.4 mm, scale factor = 100/99.4. 3) Align a board corner or mounting-hole center on ORIGIN. 4) Read hole/connector positions from the 10 mm labels. 5) Recheck hole-to-hole with calipers — paper is a layout aid, not a 0.1 mm gauge.

# PCB measurement grid — 1 mm

### A4 (210 × 297 mm) · Print at 100% / Actual size · Do NOT use Fit to page or Shrink to fit

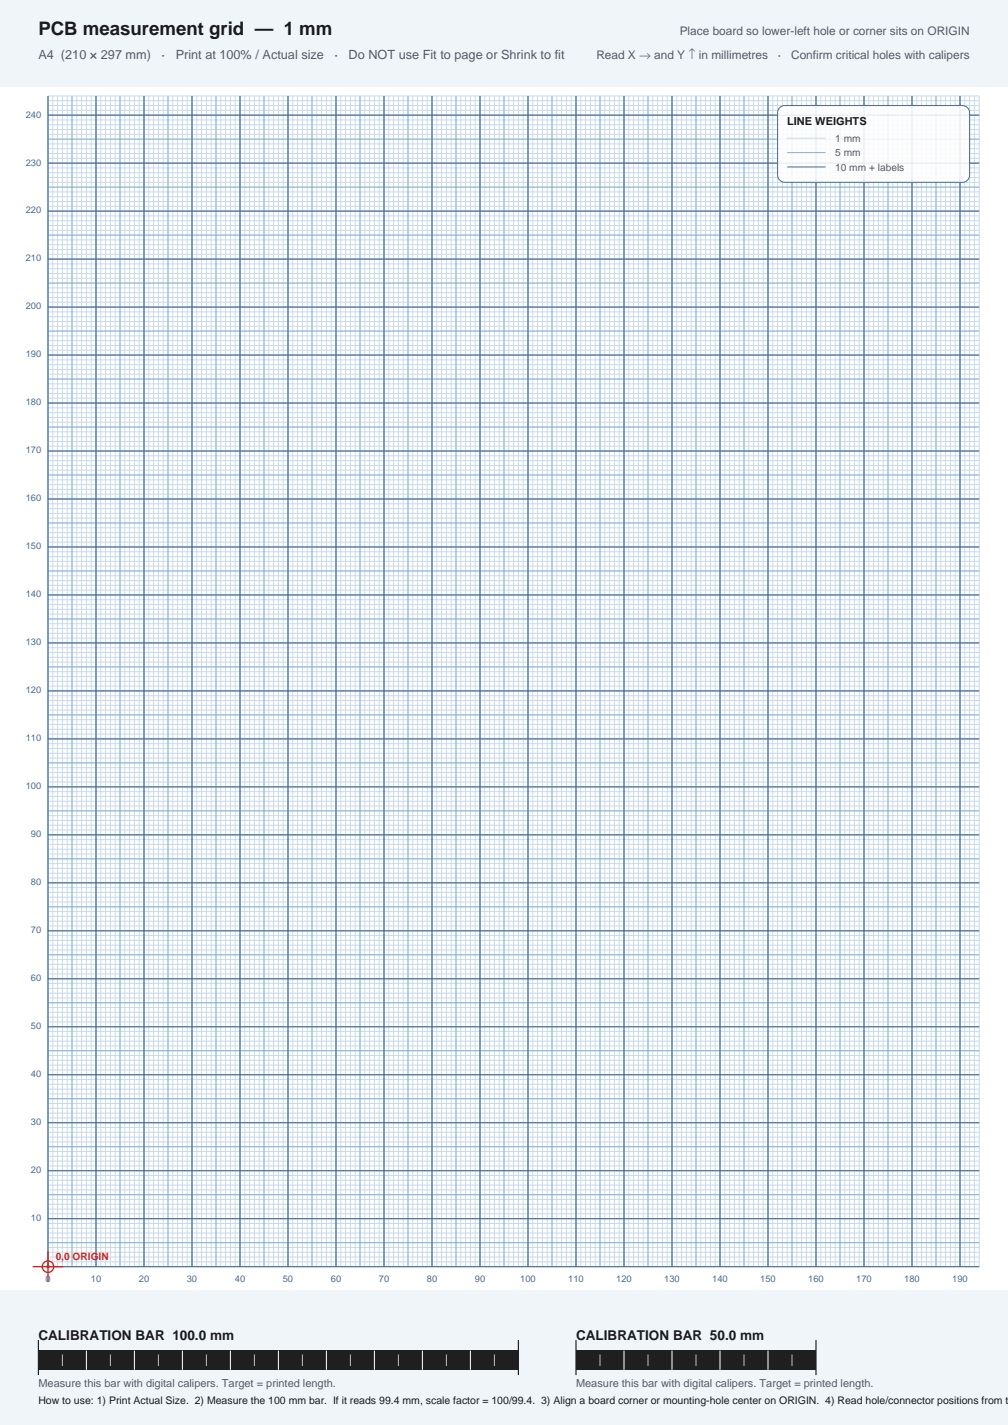
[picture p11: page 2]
0,0 ORIGIN; LINE WEIGHTS; 1 mm 5 mm 10 mm + labels

Place board so lower-left hole or corner sits on ORIGIN

Read X → and Y ↑ in millimetres · Confirm critical holes with calipers

CALIBRATION BAR 100.0 mm

CALIBRATION BAR 50.0 mm

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

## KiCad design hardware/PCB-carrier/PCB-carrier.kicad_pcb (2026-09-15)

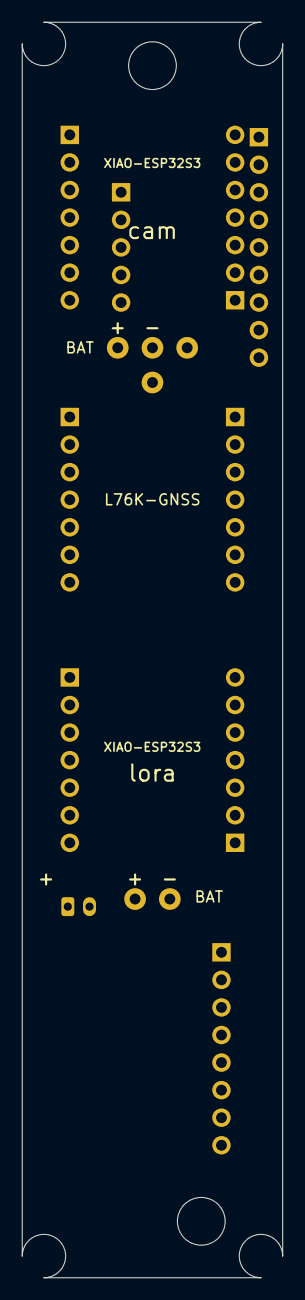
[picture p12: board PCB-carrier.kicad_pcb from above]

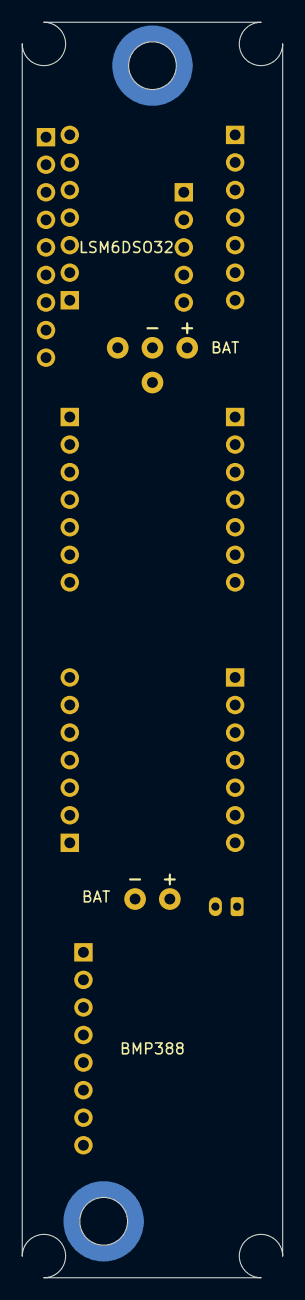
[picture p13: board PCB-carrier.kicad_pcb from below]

Board: 4 copper layers, 24.0 x 115.7 mm, 18 parts (5 on the bottom side), 9 nets, no tracks yet.

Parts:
J_BAT: JST_PH_S2B-PH-K_1x02_P2.00mm_Horizontal
J_BMP: PinHeader_1x08_P2.54mm_Vertical
J_CAM_A: PinHeader_1x07_P2.54mm_Vertical
J_CAM_B: PinHeader_1x07_P2.54mm_Vertical
J_L76K_A, J_L76K_B: PinHeader_1x07_P2.54mm_Vertical
J_LORA_A: PinHeader_1x07_P2.54mm_Vertical
J_LORA_B: PinHeader_1x07_P2.54mm_Vertical
J_LSM_A: PinHeader_1x05_P2.54mm_Vertical
J_LSM_P: PinHeader_1x09_P2.54mm_Vertical
SO1, SO2: Mounting_Wuerth_WA-SMSI-M3_H10mm_9774100360
TP_BUZ: TestPoint_THTPad_D2.0mm_Drill1.0mm
TP_BUZ_G: TestPoint_THTPad_D2.0mm_Drill1.0mm
TP_CAM_BAT_N: TestPoint_THTPad_D2.0mm_Drill1.0mm
TP_CAM_BAT_P: TestPoint_THTPad_D2.0mm_Drill1.0mm
TP_LORA_BAT_N: TestPoint_THTPad_D2.0mm_Drill1.0mm
TP_LORA_BAT_P: TestPoint_THTPad_D2.0mm_Drill1.0mm

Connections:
+3V3: J_BMP.1, J_BMP.7, J_CAM_B.5, J_LSM_P.1
+3V3_LORA: J_L76K_A.3, J_LORA_B.5
BUZZER: J_CAM_A.1, TP_BUZ.1
GND: J_BAT.2, J_BMP.3, J_CAM_B.6, J_L76K_A.2, J_LORA_B.6, J_LSM_P.3, TP_BUZ_G.1, TP_CAM_BAT_N.1, TP_LORA_BAT_N.1
GPS_RX: J_L76K_A.7, J_LORA_B.1
GPS_TX: J_L76K_B.7, J_LORA_A.7
SCL: J_BMP.4, J_CAM_A.6, J_LSM_P.4
SDA: J_BMP.6, J_CAM_A.5, J_LSM_P.5
VBAT: J_BAT.1, TP_CAM_BAT_P.1, TP_LORA_BAT_P.1

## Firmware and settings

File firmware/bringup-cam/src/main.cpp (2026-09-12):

// bringup-cam -- bench bring-up for XIAO-ESP32S3-cam + Sense-camera-board (#7)
//
// PlatformIO project, not an Arduino sketch. Build and flash:
//     pio run -t upload && pio device monitor
// Board, PSRAM and partition settings live in ../platformio.ini, so nothing
// depends on IDE menu state -- which is the point of not using a .ino.
//
// NOT FLIGHT FIRMWARE. This proves the parts are alive and talking, in the
// order that fails cheapest, and prints a PASS/FAIL line for each of #7's four
// acceptance criteria. Apogee, staging and landing detection are out of scope
// -- they need the flight profile settled first.
//
// All six steps ran on hardware 2026-09-12 and pass (hardware/XIAO-ESP32S3-cam.md,
// "On the bench"); the buzzer is measured, not self-judged -- PS1240-buzzer.md.
// Register values are cited inline so they can be checked rather than trusted.
//
// The Sense expansion board must be fitted -- camera and microSD live on it.
//
// WIRING, from docs/module-pinouts.md. Both sensors are I2C on D4/D5, powered
// from 3V3 and GND. Four wires each, Qwiic cables are bench kit:
//
//     XIAO 3V3  -> sensor VIN     <- NOT 3Vo. That is the sensor's own
//     XIAO GND  -> sensor GND        regulator output; back-feeding kills it
//     XIAO D4   -> sensor SDA
//     XIAO D5   -> sensor SCL
//     buzzer    -> D0 and GND     <- passive piezo, no supply rail
//
// TRAPS, already paid for once and recorded in module-pinouts.md:
//   - CS must be HIGH or a BMP3xx drops into SPI mode and never answers on I2C.
//     If 0x77 is silent, check CS before anything else.
//   - SDO selects the address, it is not data. High = 0x77, low = 0x76.
//   - Ignore the seller's wiring diagram. It is SPI, wired to Arduino
//     13/12/11/10, and following it wastes a session.

#include <Arduino.h>
#include <Wire.h>
#include <SPI.h>
#include "esp_camera.h"
#include "FS.h"
#include "SD.h"

// ---- pins ------------------------------------------------------------------
// D-numbers are the silkscreen labels; the GPIOs are what the compiler wants.
// Mapping confirmed off the part, 2026-09-08 -- docs/module-pinouts.md.
// What this device calls itself -- the start-up banner now, the Bluetooth name
// once firmware uses Bluetooth. The hardware page stays XIAO-ESP32S3-cam.
static const char *DEVICE_NAME = "mj-cam";

static const int PIN_SDA    = 5;    // D4
static const int PIN_SCL    = 6;    // D5
static const int PIN_BUZZER = 1;    // D0

// microSD on the Sense board, over SPI with CS on GPIO21 -- Seeed's own wiring
// and the method in their examples. An earlier revision used SD_MMC 1-bit on
// 7/9/8, which leaves CS (the card's DAT3) to chance at power-up.
static const int SD_SCK = 7, SD_MISO = 8, SD_MOSI = 9, SD_CS = 21;
// SD SPI clock. The library default is 4 MHz, and at 4 MHz the card managed
// 123 KB/s -- 6 fps of video, 8.6 s to flush 1 MB. At 20 MHz: 475 KB/s,
// 25 fps, 1 MB in 1.05 s (bench, 2026-09-12). Stated so the speeds read right.
static const uint32_t SD_HZ = 20000000;

// OV3660 on the Sense board. NOTE: this repo said OV2640 everywhere until the
// part was read off the ribbon 2026-09-06 and answered PID 0x3660. The pin map
// is the same; the sensor is not.
#define CAM_PIN_XCLK   10
#define CAM_PIN_SIOD   40
#define CAM_PIN_SIOC   39
#define CAM_PIN_D7     48
#define CAM_PIN_D6     11
#define CAM_PIN_D5     12
#define CAM_PIN_D4     14
#define CAM_PIN_D3     16
#define CAM_PIN_D2     18
#define CAM_PIN_D1     17
#define CAM_PIN_D0     15
#define CAM_PIN_VSYNC  38
#define CAM_PIN_HREF   47
#define CAM_PIN_PCLK   13

// ---- I2C parts -------------------------------------------------------------
static const uint8_t BMP388_ADDR = 0x77;   // SDO high. Low would be 0x76
static const uint8_t BMP388_CHIPID_REG = 0x00;
static const uint8_t BMP388_CHIPID = 0x50; // 0x60 would be a BMP390

static const uint8_t LSM_ADDR = 0x6A;      // 0x6B if the AD0 jumper is bridged
static const uint8_t LSM_WHOAMI_REG = 0x0F;
static const uint8_t LSM_WHOAMI = 0x6C;
static const uint8_t LSM_CTRL1_XL = 0x10;
static const uint8_t LSM_CTRL3_C  = 0x12;
static const uint8_t LSM_FIFO_CTRL3 = 0x09;
static const uint8_t LSM_FIFO_CTRL4 = 0x0A;
static const uint8_t LSM_FIFO_STATUS1 = 0x3A;
static const uint8_t LSM_OUTX_L_A = 0x28;
static const uint8_t LSM_FIFO_STATUS2 = 0x3B;   // bit6 FIFO_OVR_IA, bit3 OVR_LATCHED
static const uint8_t LSM_FIFO_DATA_OUT_TAG = 0x78;  // tag, then X_L..Z_H at 0x79-0x7E
static const uint8_t LSM_TAG_ACCEL = 0x02;          // TAG_SENSOR[7:3] for the accelerometer

// LSM6DSO32 full-scale bits are NOT the LSM6DSO's. On the -32 part:
//   FS[1:0] = 00 -> +/-4 g   01 -> +/-32 g   10 -> +/-8 g   11 -> +/-16 g
// So +/-32 g is 01, which is easy to get wrong by assuming 11 is the top range.
static const uint8_t LSM_FS_32G = 0x01;
static const float   LSM_MG_PER_LSB_32G = 0.976f;   // datasheet, +/-32 g

static bool pass_i2c = false, pass_imu = false, pass_cam = false, pass_beep = false;
static bool pass_video = false, pass_log = false;
static bool cam_ok = false, sd_ok = false;

// ---- small I2C helpers -----------------------------------------------------
static bool wr8(uint8_t addr, uint8_t reg, uint8_t val) {
  Wire.beginTransmission(addr);
  Wire.write(reg);
  Wire.write(val);
  return Wire.endTransmission() == 0;
}

static bool rd(uint8_t addr, uint8_t reg, uint8_t *buf, size_t n) {
  Wire.beginTransmission(addr);
  Wire.write(reg);
  if (Wire.endTransmission(false) != 0) return false;
  if (Wire.requestFrom((int)addr, (int)n) != (int)n) return false;
  for (size_t i = 0; i < n; i++) buf[i] = Wire.read();
  return true;
}

static int rd8(uint8_t addr, uint8_t reg) {
  uint8_t v;
  return rd(addr, reg, &v, 1) ? v : -1;
}

// ---- 1. I2C enumeration ----------------------------------------------------
static void step_i2c() {
  Serial.println(F("\n[1] I2C enumeration"));
  int found = 0;
  for (uint8_t a = 0x08; a < 0x78; a++) {
    Wire.beginTransmission(a);
    if (Wire.endTransmission() == 0) {
      Serial.printf("    found 0x%02X\n", a);
      found++;
    }
  }
  if (!found) {
    Serial.println(F("    nothing on the bus. Check VIN (not 3Vo), and check"));
    Serial.println(F("    the BMP388's CS is HIGH -- low drops it into SPI."));
    return;
  }

  int bmp = rd8(BMP388_ADDR, BMP388_CHIPID_REG);
  int lsm = rd8(LSM_ADDR, LSM_WHOAMI_REG);
  Serial.printf("    BMP388 @0x%02X chip id 0x%02X (want 0x%02X)\n",
                BMP388_ADDR, bmp, BMP388_CHIPID);
  Serial.printf("    LSM6DSO32 @0x%02X WHO_AM_I 0x%02X (want 0x%02X)\n",
                LSM_ADDR, lsm, LSM_WHOAMI);

  // #7 wants "no address clash" stated, not assumed.
  if (bmp == BMP388_CHIPID && lsm == LSM_WHOAMI) {
    Serial.println(F("    both answer, distinct addresses -- no clash"));
    pass_i2c = true;
  }
}

// ---- 2. IMU at +/-32 g with the FIFO running -------------------------------
static void step_imu() {
  Serial.println(F("\n[2] LSM6DSO32 at +/-32 g, FIFO continuous"));
  if (rd8(LSM_ADDR, LSM_WHOAMI_REG) != LSM_WHOAMI) {
    Serial.println(F("    absent, skipping"));
    return;
  }

  wr8(LSM_ADDR, LSM_CTRL3_C, 0x01);          // software reset
  delay(20);
  wr8(LSM_ADDR, LSM_CTRL3_C, 0x44);          // BDU on, IF_INC on

  // CTRL1_XL = ODR[7:4] | FS[3:2] | LPF2[1]. 833 Hz = 0b0111.
  uint8_t ctrl1 = (0x07 << 4) | (LSM_FS_32G << 2);
  wr8(LSM_ADDR, LSM_CTRL1_XL, ctrl1);
  Serial.printf("    CTRL1_XL = 0x%02X (833 Hz, +/-32 g)\n", ctrl1);

  // FIFO: batch the accel at 833 Hz, continuous mode. BOM.md calls the 9 KB
  // FIFO a hard requirement, so this is a criterion and not a nicety.
  wr8(LSM_ADDR, LSM_FIFO_CTRL3, 0x07);       // BDR_XL = 833 Hz, gyro off
  wr8(LSM_ADDR, LSM_FIFO_CTRL4, 0x06);       // FIFO_MODE = continuous
  delay(100);

  uint8_t st[2];
  uint16_t depth = 0;
  if (rd(LSM_ADDR, LSM_FIFO_STATUS1, st, 2)) {
    depth = ((uint16_t)(st[1] & 0x03) << 8) | st[0];
  }
  Serial.printf("    FIFO holds %u words after 100 ms\n", depth);

  uint8_t raw[6];
  if (rd(LSM_ADDR, LSM_OUTX_L_A, raw, 6)) {
    int16_t x = (int16_t)(raw[1] << 8 | raw[0]);
    int16_t y = (int16_t)(raw[3] << 8 | raw[2]);
    int16_t z = (int16_t)(raw[5] << 8 | raw[4]);
    Serial.printf("    accel  %.2f  %.2f  %.2f  g\n",
                  x * LSM_MG_PER_LSB_32G / 1000.0f,
                  y * LSM_MG_PER_LSB_32G / 1000.0f,
                  z * LSM_MG_PER_LSB_32G / 1000.0f);
    Serial.println(F("    sitting still, one axis should read about 1 g."));
    Serial.println(F("    If every axis reads ~0, the scale bits are wrong --"));
    Serial.println(F("    on the -32 part, 01 is +/-32 g and 11 is +/-16."));
  }
  pass_imu = (depth > 0);
}

// ---- 3. camera to microSD --------------------------------------------------
static void step_camera() {
  Serial.println(F("\n[3] camera + microSD"));
  Serial.printf("    PSRAM %s, %u bytes free\n",
                psramFound() ? "present" : "MISSING",
                (unsigned)ESP.getFreePsram());
  if (!psramFound()) {
    Serial.println(F("    build_flags in platformio.ini must carry -DBOARD_HAS_PSRAM,"));
    Serial.println(F("    or the frame buffers will not allocate."));
  }

  camera_config_t c = {};
  c.ledc_channel = LEDC_CHANNEL_0;
  c.ledc_timer   = LEDC_TIMER_0;
  c.pin_d0 = CAM_PIN_D0;  c.pin_d1 = CAM_PIN_D1;
  c.pin_d2 = CAM_PIN_D2;  c.pin_d3 = CAM_PIN_D3;
  c.pin_d4 = CAM_PIN_D4;  c.pin_d5 = CAM_PIN_D5;
  c.pin_d6 = CAM_PIN_D6;  c.pin_d7 = CAM_PIN_D7;
  c.pin_xclk = CAM_PIN_XCLK;   c.pin_pclk  = CAM_PIN_PCLK;
  c.pin_vsync = CAM_PIN_VSYNC; c.pin_href  = CAM_PIN_HREF;
  c.pin_sccb_sda = CAM_PIN_SIOD;
  c.pin_sccb_scl = CAM_PIN_SIOC;
  c.pin_pwdn = -1; c.pin_reset = -1;
  c.xclk_freq_hz = 20000000;          // the ~20 MHz XCLK the ribbon may not be
  c.frame_size   = FRAMESIZE_SVGA;    // extended -- see Sense-camera-board.md
  c.pixel_format = PIXFORMAT_JPEG;
  c.grab_mode    = CAMERA_GRAB_WHEN_EMPTY;
  c.fb_location  = CAMERA_FB_IN_PSRAM;
  c.jpeg_quality = 12;
  c.fb_count     = 2;

  esp_err_t err = esp_camera_init(&c);
  if (err != ESP_OK) {
    Serial.printf("    camera init failed 0x%x -- is the Sense board seated?\n", err);
    return;
  }
  sensor_t *s = esp_camera_sensor_get();
  if (s) Serial.printf("    sensor PID 0x%04X (OV3660 = 0x3660)\n", s->id.PID);
  cam_ok = true;

  SPI.begin(SD_SCK, SD_MISO, SD_MOSI, SD_CS);
  if (!SD.begin(SD_CS, SPI, SD_HZ)) {
    Serial.println(F("    microSD did not mount. Card seated? FAT32?"));
    return;
  }
  sd_ok = true;

  camera_fb_t *fb = esp_camera_fb_get();
  if (!fb) { Serial.println(F("    capture returned nothing")); return; }

  File f = SD.open("/bringup.jpg", FILE_WRITE);
  if (f) {
    f.write(fb->buf, fb->len);
    f.close();
    Serial.printf("    wrote /bringup.jpg, %u bytes, %ux%u\n",
                  (unsigned)fb->len, fb->width, fb->height);
    pass_cam = true;
  } else {
    Serial.println(F("    could not open the file for writing"));
  }
  esp_camera_fb_return(fb);

  // design.md: nothing writes the card during boost. Proving a flush works on
  // the bench is the point; the flight rule is a firmware decision, not this.
  Serial.println(F("    (flight rule: no card writes during boost -- PSRAM buffer, flush after)"));
}

// ---- 4. video: frames straight to one MJPEG file on the card ---------------
// A concatenation of JPEG frames is a valid MJPEG stream -- `ffplay` or VLC
// plays it. The number that matters is the per-frame write time: SD latency is
// unbounded (microSD.md), and the worst case is what a recorder must survive.
static void step_video() {
  Serial.println(F("\n[4] video -- 5 s of 800x600 frames to /bringup.mjpeg"));
  if (!cam_ok || !sd_ok) { Serial.println(F("    needs the camera and the card, skipping")); return; }
  File f = SD.open("/bringup.mjpeg", FILE_WRITE);
  if (!f) { Serial.println(F("    could not open the file")); return; }
  uint32_t frames = 0, bytes = 0, w_sum = 0, w_max = 0, t_end = millis() + 5000;
  uint32_t t0 = millis();
  while ((int32_t)(millis() - t_end) < 0) {
    camera_fb_t *fb = esp_camera_fb_get();
    if (!fb) continue;
    uint32_t w0 = micros();
    size_t n = f.write(fb->buf, fb->len);
    uint32_t w = micros() - w0;
    esp_camera_fb_return(fb);
    if (n != fb->len) { Serial.println(F("    short write -- card full or failing")); break; }
    frames++; bytes += n; w_sum += w; if (w > w_max) w_max = w;
  }
  f.close();
  float secs = (millis() - t0) / 1000.0f;
  Serial.printf("    %u frames in %.1f s = %.1f fps, %u bytes (%.0f KB/s)\n",
                frames, secs, frames / secs, bytes, bytes / 1024.0f / secs);
  if (frames) Serial.printf("    card write per frame: mean %.1f ms, worst %.1f ms\n",
                            w_sum / 1000.0f / frames, w_max / 1000.0f);
  pass_video = frames >= 10;
}

// ---- 5. the flight log's path: IMU FIFO -> PSRAM -> card -> read back -------
// design.md: no card writes during boost; buffer in PSRAM, flush after landing.
// This fills a 1 MB PSRAM buffer the way a recorder would -- 3 s of FIFO words,
// the rest a known pattern -- then flushes it in one go and reads it back.
static void step_log() {
  Serial.println(F("\n[5] PSRAM log -- 3 s of IMU FIFO, flushed to /imulog.bin, read back"));
  if (!sd_ok || rd8(LSM_ADDR, LSM_WHOAMI_REG) != LSM_WHOAMI) {
    Serial.println(F("    needs the card and the LSM6DSO32, skipping")); return;
  }
  const size_t CAP = 1024 * 1024;
  uint8_t *buf = (uint8_t *)ps_malloc(CAP);
  if (!buf) { Serial.println(F("    ps_malloc(1 MB) failed -- PSRAM not usable")); return; }

  wr8(LSM_ADDR, LSM_FIFO_CTRL4, 0x00);       // bypass: empties the FIFO
  wr8(LSM_ADDR, LSM_FIFO_CTRL4, 0x06);       // continuous again, 833 Hz accel (step 2)
  size_t used = 0; uint32_t words = 0, bad_tag = 0; bool overrun = false;
  uint32_t t0 = millis();
  while (millis() - t0 < 3000 && used + 7 <= CAP) {
    uint8_t st[2];
    if (!rd(LSM_ADDR, LSM_FIFO_STATUS1, st, 2)) continue;
    if (st[1] & 0x48) overrun = true;        // FIFO_OVR_IA or OVR_LATCHED: samples lost
    uint16_t n = ((uint16_t)(st[1] & 0x03) << 8) | st[0];
    while (n-- && used + 7 <= CAP) {
      if (!rd(LSM_ADDR, LSM_FIFO_DATA_OUT_TAG, buf + used, 7)) break;
      if ((buf[used] >> 3) != LSM_TAG_ACCEL) bad_tag++;
      used += 7; words++;
    }
  }
  float secs = (millis() - t0) / 1000.0f;
  double mag = 0;                             // mean |a|, a sanity check on the data
  for (size_t i = 0; i < used; i += 7) {
    int16_t x = buf[i+2] << 8 | buf[i+1], y = buf[i+4] << 8 | buf[i+3], z = buf[i+6] << 8 | buf[i+5];
    mag += sqrt((double)x*x + (double)y*y + (double)z*z) * LSM_MG_PER_LSB_32G / 1000.0;
  }
  if (words) mag /= words;
  Serial.printf("    %u words in %.2f s = %.0f Hz (want ~833), bad tags %u, overrun %s\n",
                words, secs, words / secs, bad_tag, overrun ? "YES -- samples lost" : "no");
  Serial.printf("    mean |a| = %.3f g (want ~1 at rest)\n", mag);

  for (size_t i = used; i < CAP; i++) buf[i] = (uint8_t)(i * 31 + 7);   // known pattern
  File f = SD.open("/imulog.bin", FILE_WRITE);
  if (!f) { Serial.println(F("    could not open /imulog.bin")); free(buf); return; }
  uint32_t w0 = millis();
  size_t wrote = f.write(buf, CAP);
  f.close();
  uint32_t wms = millis() - w0;
  Serial.printf("    flushed %u bytes in %u ms = %.0f KB/s\n", wrote, wms, wrote / 1.024f / (wms ? wms : 1));

  f = SD.open("/imulog.bin", FILE_READ);
  size_t same = 0, got = 0; static uint8_t chunk[4096];   // static: off the 8 KB loop stack
  while (f && got < CAP) {
    size_t n = f.read(chunk, sizeof chunk);
    if (!n) break;
    for (size_t i = 0; i < n; i++) same += (chunk[i] == buf[got + i]);
    got += n;
  }
  if (f) f.close();
  Serial.printf("    read back %u bytes, %u match\n", got, same);
  free(buf);
  float want = 833.0f * secs;
  pass_log = wrote == CAP && got == CAP && same == CAP && !overrun && bad_tag == 0
             && words > want * 0.9f && words < want * 1.1f;
}

// ---- 6. buzzer, two distinguishable tones ----------------------------------
static void beep(int hz, int ms) {
  ledcAttach(PIN_BUZZER, hz, 10);
  ledcWrite(PIN_BUZZER, 512);          // 50% duty; a passive piezo needs AC
  delay(ms);
  ledcWrite(PIN_BUZZER, 0);
  ledcDetach(PIN_BUZZER);
  delay(120);
}

static void step_buzzer() {
  Serial.println(F("\n[6] buzzer on D0 -- two patterns"));
  Serial.println(F("    ARMED  : three short high chirps"));
  for (int i = 0; i < 3; i++) beep(3000, 90);
  delay(400);
  Serial.println(F("    FAULT  : two long low tones"));
  for (int i = 0; i < 2; i++) beep(1200, 400);
  Serial.println(F("    Silence means the piezo is ACTIVE, not passive --"));
  Serial.println(F("    an active buzzer wants DC and ignores PWM."));
  pass_beep = true;                    // no way to hear it from here: you judge
}

void setup() {
  Serial.begin(115200);
  delay(2000);                         // USB CDC needs a moment to enumerate
  Serial.printf("\n=== %s -- bringup-cam : XIAO-ESP32S3-cam + Sense-camera-board ===\n", DEVICE_NAME);
  Serial.println(F("=== js-rocket-avionics #7. Bench only, not flight firmware ==="));

  Wire.begin(PIN_SDA, PIN_SCL, 400000);

  step_i2c();
  step_imu();
  step_camera();
  step_video();
  step_log();
  step_buzzer();

  Serial.println(F("\n=== #7 acceptance criteria ==="));
  Serial.printf("  both sensors enumerate and stream        %s\n", pass_i2c  ? "PASS" : "FAIL");
  Serial.printf("  IMU at +/-32 g with FIFO active          %s\n", pass_imu  ? "PASS" : "FAIL");
  Serial.printf("  one camera frame to microSD              %s\n", pass_cam  ? "PASS" : "FAIL");
  Serial.printf("  video to microSD                          %s\n", pass_video ? "PASS" : "FAIL");
  Serial.printf("  PSRAM log flushed and read back          %s\n", pass_log  ? "PASS" : "FAIL");
  Serial.println(F("  two distinguishable beep patterns        YOU JUDGE -- did you hear both?"));
  Serial.println(F("\nRecord the result on #7. A FAIL here is a finding, not a setback."));
}

void loop() {
  delay(10000);
}

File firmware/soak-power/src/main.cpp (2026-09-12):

// soak-power -- the load half of #8, on XIAO-ESP32S3-cam + Sense-camera-board
// https://github.com/jwilleke/js-rocket-avionics/issues/8
//
// NOT FLIGHT FIRMWARE, and not a bring-up either -- run bringup-cam first and
// get four PASSes out of it. This project assumes the parts are known good and
// asks one question instead: what does the shared battery do when the camera is
// working, and does XIAO-ESP32S3-lora survive it.
//
// #8 exists because BOM.md accepts "a camera brownout on B can disturb A" in
// writing and nobody has ever seen it happen. The scope answer is better; this
// is what to run when the scope is not there, and it is worth running anyway
// because it logs for an hour and a scope trace does not.
//
// WHAT IT DOES
//   Drives the worst load the flight build can produce -- capture, then an SD
//   write burst, as fast as the card takes it -- and appends ONE CSV LINE PER
//   CYCLE to the card. The record is on the card rather than in RAM or on the
//   serial port precisely because the event being hunted is a reset.
//
// THE TRAP THAT WOULD WASTE THE SESSION
//   USB-C powers the board. A run with the monitor attached is a run on the
//   bench supply, and it measures nothing about the battery. Flash over USB,
//   UNPLUG, then run from the battery and read the card afterwards.
//
// WHAT COMES OUT
//   /soak-power.csv, one line per cycle plus a line per boot. Every boot line
//   carries esp_reset_reason(), so a brownout names itself: the ESP32-S3's own
//   detector fires before the CPU misbehaves, and ESP_RST_BROWNOUT in that
//   column is the observation #8 is missing. Count the boot lines, read the
//   last uptime before each, and the endurance question falls out of the same
//   file -- see the header comment in soak_open_log() for the columns.
//
// WIRING
//   Nothing is required beyond a card in the slot. The optional battery divider
//   -- see platformio.ini -- adds the voltage columns, which turn "it reset"
//   into "it reset at 3.1 V during a 42 ms write". Without it the reset is
//   still caught and still attributed; only the shape of the sag is missing.

#include <Arduino.h>
#include <esp_system.h>
#include "esp_camera.h"
#include "FS.h"
#include <SPI.h>
#include "SD.h"
#include <Preferences.h>

// ---- configuration, all overridable from platformio.ini --------------------
#ifndef SOAK_FRAMESIZE
#define SOAK_FRAMESIZE FRAMESIZE_SVGA   // matches bringup-cam. UXGA is harsher
#endif
#ifndef SOAK_PERIOD_MS
#define SOAK_PERIOD_MS 0                // 0 = flat out, which is the worst case
#endif
#ifndef SOAK_BEEP_EVERY
#define SOAK_BEEP_EVERY 0               // chirp every N cycles; 0 = silent
#endif

// Frames go round-robin into a fixed set of files. The write burst is the load;
// keeping every frame would only fill the card and stop the run early.
static const int   SOAK_FRAME_FILES = 16;
static const char *LOG_PATH = "/soak-power.csv";

// ---- pins, from docs/module-pinouts.md and bringup-cam ---------------------
static const int PIN_BUZZER = 1;                 // D0
// Sense microSD over SPI, CS on GPIO21 -- Seeed's wiring, proven by bringup-cam
// on 2026-09-12. SD_MMC 1-bit on 7/9/8 was never run and leaves CS to chance.
static const int SD_SCK = 7, SD_MISO = 8, SD_MOSI = 9, SD_CS = 21;

#define CAM_PIN_XCLK   10
#define CAM_PIN_SIOD   40
#define CAM_PIN_SIOC   39
#define CAM_PIN_D7     48
#define CAM_PIN_D6     11
#define CAM_PIN_D5     12
#define CAM_PIN_D4     14
#define CAM_PIN_D3     16
#define CAM_PIN_D2     18
#define CAM_PIN_D1     17
#define CAM_PIN_D0     15
#define CAM_PIN_VSYNC  38
#define CAM_PIN_HREF   47
#define CAM_PIN_PCLK   13

// ---- state that outlives a reset -------------------------------------------
// RTC memory survives a software reset and deep sleep. It may NOT survive a
// brownout, which is the case this firmware is built around -- so it is a
// convenience for the serial line, and the CSV on the card is the real record.
// Do not compute endurance from these; count boot lines in the file.
RTC_NOINIT_ATTR static uint32_t rtc_magic;
RTC_NOINIT_ATTR static uint32_t rtc_boots;
static const uint32_t RTC_MAGIC = 0x50575231;   // "PWR1"

// ---- reset history in NVS, independent of the card --------------------------
// Bench, 2026-09-12: a reset in the middle of a card write left the card
// unmountable until its power was cut. The event this project hunts is a reset,
// so the card cannot be the only record of it. Every boot appends its reset
// reason, and the uptime the previous boot reached, to a 32-entry ring in NVS;
// every boot prints the ring. Uptime is saved every 30 s -- ~120 NVS writes an
// hour, nothing against the flash's endurance.
static Preferences nvs;
struct BootRec { uint8_t reason; uint32_t prev_up_s; };
static const int HIST = 32;
static uint32_t last_up_save = 0;

static uint32_t boot_id  = 0;
static uint32_t cycle    = 0;
static bool     have_sd  = false;
static bool     have_cam = false;

// ---- optional battery sampling ---------------------------------------------
// A blocking SD write cannot sample its own supply, so when a divider is fitted
// a second task on the other core samples continuously and keeps a min/max
// window that the main loop drains once per cycle. That window is what catches
// inrush sag: an average across a cycle hides exactly the dip being looked for.
#ifdef SOAK_VBAT_PIN
static volatile int v_min_mv = INT32_MAX;
static volatile int v_max_mv = 0;

static int vbat_mv() {
  return (int)(analogReadMilliVolts(SOAK_VBAT_PIN) * (float)SOAK_VBAT_DIVIDER);
}

static void vbat_task(void *) {
  for (;;) {
    int mv = vbat_mv();
    if (mv < v_min_mv) v_min_mv = mv;
    if (mv > v_max_mv) v_max_mv = mv;
    vTaskDelay(1);                  // ~1 kHz, fast enough for an SD write burst
  }
}

// Returns the window and starts a fresh one.
static void vbat_window(int *lo, int *hi) {
  *lo = (v_min_mv == INT32_MAX) ? 0 : v_min_mv;
  *hi = v_max_mv;
  v_min_mv = INT32_MAX;
  v_max_mv = 0;
}
#endif

// ---- reset reason ----------------------------------------------------------
// ESP_RST_BROWNOUT is the whole point of this firmware. The others are here so
// that a reset which is NOT a brownout cannot be mistaken for one -- a panic
// caused by a bug in this file would otherwise read as evidence about the battery.
static const char *reset_name(esp_reset_reason_t r) {
  switch (r) {
    case ESP_RST_POWERON:  return "POWERON";
    case ESP_RST_EXT:      return "EXT";
    case ESP_RST_SW:       return "SW";
    case ESP_RST_PANIC:    return "PANIC";
    case ESP_RST_INT_WDT:  return "INT_WDT";
    case ESP_RST_TASK_WDT: return "TASK_WDT";
    case ESP_RST_WDT:      return "WDT";
    case ESP_RST_DEEPSLEEP:return "DEEPSLEEP";
    case ESP_RST_BROWNOUT: return "BROWNOUT";
    case ESP_RST_SDIO:     return "SDIO";
    default:               return "UNKNOWN";
  }
}
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

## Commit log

2026-08-06 feat(hardware): carrier PCB outline, stackup and mounting holes
    Stage 2a of the avionics plan. Mechanical envelope only -- no schematic, no
    placement, no routing. The Gerbers in fab/ describe an empty board and exist
    to prove the toolchain, not to be ordered.
    This is deliberately first because the js-rocket sled generator derives its
    rail bosses from these numbers, so the outline has to freeze before the
    printed part can be designed.
    Board is 24.000 x 70.000 mm, 1.0 mm, 4 copper layers, 2.0 mm corner radius,
    four M2 clearance holes at (3,3) (21,3) (3,67) (21,67). Verified from the
    exported Gerber and drill files rather than the generator's own output. DRC
    reports 0 violations.
    Generated t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
    [carrier-Edge_Cuts.dxf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]
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2026-08-06 feat(hardware): nets, XIAO headers and inner planes; board 24x70 -> 24x95
    Stage 2b, partially. DRC clean at 0 violations, 0 unconnected -- and that
    result now means something, because the board has a netlist to check. Before
    this it was decorative copper and "0 unconnected" was vacuous.
    The board had to grow. 70 mm assumed the two XIAOs could overlap in plan view,
    one per face. They cannot: these are through-hole headers so the holes pass
    through the board, and XIAO A uses D6/D7 for the GPS UART while XIAO B uses
    D4/D5 for I2C -- different nets on the same holes. End to end, the bottom face
    needs XIAO 21 + LSM6DSO32 25.5 + BMP390 25.5 + buzzer, about 84 mm, and at
    24 mm wide against 17.8 mm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
    [carrier-Edge_Cuts.dxf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]
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2026-08-09 docs: add BOM.md and shopping-list.md
    BOM.md owns the engineering facts: what each part is, which board it
    serves, mass, size, why it was chosen, what was rejected and why, and the
    chip-ID check to run before designing a footprint round anything.
    shopping-list.md owns the receipts: SKU, vendor, order number, cost,
    arrival status, and what is blocking the copper order.
    Both were missing. The rocket repo's shopping-list.md had been linking to
    docs/BOM.md while docs/ was empty, and three orders totalling $104.48 —
    placed 2026-08-06/07 — were recorded nowhere at all.
    Board A shipped 2026-08-07: XIAO ESP32S3 & Wio-SX1262 Kit (102010611),
    $10.90, antennas included, pre-flashed Meshtastic. A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
2026-08-09 docs: 4000564800 shipped from the US warehouse, and shipped first
    The shipping notice existed and the first pass through the mail missed it:
    2026-08-07, USPS 420430509261290198196828213362, United States warehouse —
    an hour before 4000564803. Only the invoice email is genuinely absent, and
    that is the one carrying line items, so the contents are still unknown.
    This inverts the arrival order. US warehouse on USPS is days; 4000564803
    ships YanWen from China at 7-15 working days. The unidentified box is the
    first one to land, and it is believed to hold board B's MCU and the GPS.
    Also recorded: 4000564803 tracks as YanWen UL400424782YP, and both Seeed
    orders carry AIG insurance at 100% of it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
2026-08-10 docs: LSM6DSO32, buzzer and cell in hand 2026-08-10
    The Adafruit box arrived a day early. With the BMP388 already on the bench
    that is both I2C sensors in hand, and the LSM6DSO32's header order was the
    last unknown blocking sensor footprints. Qwiic cables ship with both, so
    the breadboard needs no soldering.
    Measure the LSM6DSO32 and photograph its header before designing its
    footprint — this project has already had one board disagree with Adafruit's
    published dimensions in two places.
2026-08-11 docs: Sense and L76K in hand — board B is fully on the bench
    Seeed 4000564800 delivered 2026-08-11, the US-warehouse box. Only board A's
    radio is still in transit (4000564803, YanWen from China, ~08-17 to 08-26).
    The blocking list is re-sequenced around what that unlocks. Four steps are
    no longer gated on anything: weigh the four new parts, breadboard board B in
    full, photograph every header before drawing a footprint, and check the
    L76K's own geometry against the claim that it plugs onto the XIAO's 14 pads
    rather than presenting a header to the carrier.
    Weighing is the highest-value item. The ~51.4 g avionics figure is what the
    rocket's ballast decision rests on, and the one estimate al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
2026-08-11 docs: microSD is in hand, and its A1/A2 spec no longer binds
    Several cards are held, so it comes off the buy list. The A1/A2 or
    industrial-pSLC requirement was written when the 500 Hz sampler wrote to
    the card during flight, where a 100-250 ms stall dropped samples. PSRAM
    buffering removed that: nothing touches the card until after landing. What
    is left is sequential video write, which is a speed-class question rather
    than the random-IOPS question A1/A2 answers.
    Also fixed while in the file: BOM.md still pointed at the rocket repo's
    electronics-plan.md as the design record, which moved here as design.md at
    v7.7.31; and it still quoted the superseded 0.78 g ballast ratio.
    The 2x7 stacking h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
2026-08-11 docs(arming): record the reed switch's two open decisions
    The design record carried the architecture — reed switch in the battery
    line, not on a GPIO — but neither the part type nor the switching topology
    follows from it, and both were unwritten.
    OPEN 1, polarity. Normally-open vs normally-closed is undecided, and it
    inverts the field procedure. Normally-closed with the magnet SAFING is the
    standard pattern and the one to adopt: a magnet taped to the nose holds the
    contacts open, pulling it off at the pad arms the rocket, it fails safe,
    and the magnet doubles as a remove-before-flight tag. Normally-open would
    need the magnet held on for the whole flight. NC reeds are much less common
    th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
2026-08-14 docs: board A's radio is in hand — no parcel gates the carrier PCB now
    Seeed 4000564803 delivered 2026-08-13, four days ahead of the 08-17
    earliest estimate. Every ordered avionics part is on the bench.
    The one measurement the layout waits on — whether the L76K clears the
    Wio-SX1262 on the B2B — is now takeable. If they cannot share the XIAO
    stack the GPS returns as a carrier footprint needing ~21 mm, which the
    95 mm board has, so it decides layout rather than board size.
    Also fixes two stale "LSM6DSO32 has not arrived" claims in README.md and
    module-pinouts.md; it landed 2026-08-10 and is still unmeasured.
2026-08-15 docs(resources): brainstorm — replace the reed switch with a removable plug
    Working notes from 2026-08-15, recorded because one item replaces an
    architecture rather than adjusting it, and the rest would otherwise be
    lost.
    A switched 3.5 mm jack arms natively: normalled contact closed with no
    plug, opening when one is inserted. Plug in = safe, plug out = armed,
    and the plug carries no wires -- a dummy key with the RBF flag on it.
    It dissolves both open questions in design.md rather than answering
    them. Magnet orientation, the ~20 mm field gap from the carrier's centre
    plane, the 32 g steel ballast distorting the field, the welded-contact
    failure mode that leaves an armed rocket that canno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
2026-08-15 docs(resources): pull-pin and a microswitch, and correct the MOSFET claim
    Direction chosen: a pin / pull-tab holding a subminiature snap-action
    microswitch. Pin in, plunger held, circuit open, SAFE. Pin out, circuit
    closed, ARMED. RBF streamer on the pin.
    It beats both the reed and the jack on the constraint measured earlier:
    ~2-3 mm hole against 6 mm for a jack and 9 x 3.2 mm for USB-C, and a few
    mm of intrusion into the recovery cord's path against 12-14 mm for a
    jack. Snap action gives defined make/break with no chatter and avoids
    the oxidation that plagues DIY leaf contacts. Many subminiature
    microswitches are rated 3-5 A, above the ~300 mA steady draw and the
    camera inrush, so the pin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
2026-08-17 docs(bom): weigh nine parts, and make BOM.md the single source of truth
    Nine parts weighed 2026-08-17. Net +4.1 g against the estimates, and it
    is one part: the L76K GNSS is 14.2 g against a 5.0 g estimate (+184%),
    now the heaviest object in the nose. Four rows came in light (Sense
    -3.5, Wio-SX1262 -2.4, buzzer -1.4, XIAO -0.6) and still did not cover
    it. Both Adafruit STEMMA QT sensors are 1.8 g against 1.0 g estimates,
    +80% each, so the BMP388's overrun was the form factor and not a fluke.
    Nose total 51.4 -> 54.7 g against a ~50 g target and a ~65 g weathercock
    limit. Over target, under the limit.
    Restructure so there is exactly one place to look:
    - BOM.md leads with Part / Part number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
2026-09-05 docs: regenerate TODO.md from issue labels
    Standard label set applied with utility/sync-labels.sh -- the repo had only
    GitHub's defaults, so nothing could be banded. Two epics and their sub-issues
    now carry priorities: #4 (bench bring-up) gates #11 (order the carrier PCB).
    Claude-Session: https://claude.ai/code/session_01UxgSyTFhLrU452nN786crc
2026-09-05 docs(hardware): one page per electronics part
    Thirteen part pages plus an index, following the js-rocket 3d-printed-parts
    pattern: what the part is, what it is for, its interfaces, the traps, and what
    is still open on it with the issue that tracks it.
    These pages deliberately carry no part numbers and no masses. BOM.md owns both
    and says so -- a number in two places is a number that will disagree with
    itself -- so every page links there instead.
    Two things surfaced while writing them:
    - design.md's locked-decisions table still names the reed switch, superseded
    2026-08-15 by the pull-pin and microswitch. Recorded on Arming-switch.md.
    - design.md places board B on the "bottom" face and ne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
2026-09-05 docs: M2 is the fastener standard, not a per-board reading
    Operator, 2026-09-05: M3 does not fit these breakouts and nothing 2.5 mm is
    being bought, so every board mounting screw is M2.
    That takes hole diameter off the open list. A board's measured hole only has
    to clear an M2; it is not an input to the footprint. Recorded once in
    hardware/README.md and referenced from the part pages rather than restated.
    What is still owed per board is hole SPACING -- two holes cannot be placed
    without their centres -- plus board length, width and thickness. Corrected the
    LSM6DSO32 page and module-pinouts.md, which both overstated what is missing.
    Refs #5, #14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
2026-09-06 docs: LSM6DSO32 spacing and thickness, and 2.54 mm pitch confirmed
    Operator readings 2026-09-05: hole spacing 20.58 mm (provisional, "appears to
    be"), thickness over the Qwiic connectors 4.80 mm, and 2.54 mm header pitch
    confirmed on the BMP388 and the XIAO.
    20.58 and 4.80 are the BMP388's 20.58 and 4.79 -- indistinguishable at this
    precision -- so the carrier needs ONE hole pattern placed twice: two M2
    clearance holes at 20.58 mm centres. What differs is the rotation, not the
    drilling. The BMP388's holes are on the edge opposite its header; the
    LSM6DSO32's are on its Aux edge with the Primary row opposite.
    With pitch confirmed there is a check worth recording: the 9-pin Primary row
    spans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
2026-09-06 docs: Y offsets measured, and the footprint is no longer blocked
    Operator, 2026-09-06, both boards identical: header row centreline 2.54 mm
    from its near long edge, mounting-hole centreline 14.65 mm from the far long
    edge, holes 2.54 mm in from each short side.
    Two checks, one clean and one not:
    - The hole readings close exactly -- 14.65 + 3.15 = 17.80, the measured width.
    - The header pair does not. 2.54 + 15.75 = 18.29 against 17.80, 0.49 mm over,
    so one is not edge-to-centre. Using 2.54 and deriving 15.26; the 15.75 was
    most likely taken to the far side of the hole rather than its centre.
    Hole spacing also has two routes 0.16 mm apart -- 20.42 from the short-side
    inset against 20.5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
2026-09-06 docs: six grid photographs, and three things they show
    Renamed on the way in: BMO388-front.jpg -> BMP388-front-grid.jpg,
    -antenas -> -antennas, and the two Sense files named for what they actually
    show -- one is the expansion board with the camera, the other is the MCU
    module.
    Three findings:
    - The camera ribbon appears to read OV36.., not OV2640. Partly obscured by the
    fold, so flagged rather than asserted -- but if it is an OV3660 then the
    4.482 mm diagonal, the f4.8 lens and the 50.1 deg cone are all wrong, and
    with them the port sizing in js-rocket#88 and the shelf radius in #89.
    Read it with the ribbon unfolded, or query the sensor ID over I2C in #7.
    - The LoRa "82 mm whip" is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
2026-09-08 fix(carrier): unmirror the +8.5 header row, and make the read-back a check that runs
    Closes the mapping half of #18. +3V3 and GND were landing on D9 and D8 and
    GPS_RX on the 5V pin -- 5 of 9 net placements wrong, all on the +8.5 row.
    THE BUG. add_xiao() numbered row two 15 - i, which is correct, and then placed
    it at cy - offset, which mirrors it end for end. Pin p ended up at
    cy + (p-11)*2.54 where RF_Module:MCU_Seeed_ESP32C3 puts it at cy - (p-11)*2.54.
    Numbered the right way round, placed the wrong way round. Now i + 7, which
    reads the way the docstring always described it.
    THE REAL FIX IS verify_pins(), AND THE POINT OF IT IS THAT IT RUNS. Two
    revisions of this file have now shipped a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
    [carrier.kicad_pcb]
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2026-09-08 feat(firmware): bring-up sketch for the Sense stack, and one bench procedure for #4
    #4 blocks #11, which is the order. Its three open children -- #6, #7, #8 -- are
    bench work, and #7 could not start at all: BOM.md lists that firmware as
    "custom, and not yet started", and the repo had no firmware directory.
    TWO DELIVERABLES.
    firmware/bringup-cam/bringup-cam.ino -- runs #7's four acceptance criteria in
    the order that fails cheapest and prints PASS/FAIL for each. I2C enumeration
    with both chip IDs checked, LSM6DSO32 at +/-32 g with the FIFO filling, camera
    to microSD via SD_MMC 1-bit, two buzzer patterns on D0. NOT flight firmware --
    apogee, staging and landing detection need the flight profi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
    [bringup-cam.ino]
2026-09-08 refactor(firmware): PlatformIO project, no .ino
    Operator, 2026-09-08: no .ino files, use PlatformIO.
    firmware/bringup-cam/bringup-cam.ino -> firmware/bringup-cam/src/main.cpp
    + firmware/bringup-cam/platformio.ini
    + firmware/README.md
    WHY IT MATTERS HERE RATHER THAN BEING A PREFERENCE. A sketch carries its build
    configuration in IDE menu state -- board, PSRAM, partition table -- and none of
    it is in the file. This project has two settings that are load-bearing and
    whose failure does not look like a settings problem:
    -DBOARD_HAS_PSRAM the camera allocates frame buffers in PSRAM, and
    without it esp_camera_init returns an error that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
    [main.cpp]
2026-09-08 feat(firmware): soak-power, the load and the record for the shared-cell test
    [#8](https://github.com/jwilleke/js-rocket-avionics/issues/8) has been an
    accepted risk in BOM.md for weeks -- "a camera brownout on B can disturb A" --
    and the reason it stayed a prediction is that observing it wanted a scope on the
    bench at the moment the camera wrote. This is what to run when the scope is not
    there, and it beats one anyway on the axis that matters here: it logs for an
    hour.
    firmware/soak-power drives the worst load the flight build can produce, capture
    then an SD write burst as fast as the card takes it, and appends one CSV line
    per cycle to /soak-power.csv plus a line per boot carrying esp_rese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
    [main.cpp]
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2026-09-08 docs: it is the battery, not "the cell"
    Operator, 2026-09-08. Part names come from the page names under hardware/, and
    where a page has a plain-English word for the thing, that word is the one to
    use. "Cell" is datasheet vocabulary. It reads as jargon to everyone who has to
    work on this, and one battery made of one cell gains nothing by the distinction.
    79 occurrences across 17 files, plus the title of
    [#8](https://github.com/jwilleke/js-rocket-avionics/issues/8), which was "Both
    MCUs on one cell with the camera running" and is now "on one battery". The
    LiPo-500mAh page's own heading said "LiPo cell".
    The rule now lives where the rest of the vocabulary does, at the top of
    hardware/README.m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
    [main.cpp]
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2026-09-09 refactor(hardware): the KiCad sources move in beside the page that documents them
    hardware/carrier/ held the board and hardware/PCB-carrier/ held the page about
    the board -- two folders, one part, and a folder named "carrier" which the name
    list adopted yesterday does not contain. Merged into PCB-carrier/.
    Repointed everything that knew the old path: both generators' OUT constant, and
    the three CLI recipes in the repo README that run DRC and export gerbers and
    drill files. Verified the generators resolve to a directory that exists and a
    board file that is in it.
    .kicad_prl is gitignored local editor state, so it moved outside git rather than
    with it -- worth knowing, because `git mv` on al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
    [carrier.kicad_pcb]
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2026-09-10 fix(carrier): net the bottom-face XIAO from its back, and draw the carrier
    gen_carrier.py netted both XIAOs from one front-view pin table.
    XIAO-ESP32S3-cam sits on the bottom face and presents its back to the
    shared through-holes, so its rows were swapped: BUZZER on the 5V pin,
    +3V3 and GND on D2 and D1, SDA/SCL on D9/D8. XIAO-ESP32S3-lora, on the
    top face, was always right.
    - Each XIAO's face is declared once (XIAO_*_FACE). add_xiao() mirrors x
    for the bottom face; y and the USB-C-aft orientation do not change.
    The cam's pins 1..7 move from the x = 3.5 row to 20.5.
    - verify_pins() also checks every net against the underside-photo
    reading in module-pinouts.md, by signal name. Putting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
    [PCB-carrier.kicad_pcb]
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2026-09-11 fix(carrier): standoff 1 to the board's aft end, clear of every module
    It sat under XIAO-ESP32S3-cam, between the pin rows, where its 4.4 mm
    board hole met the BAT pigtail in the gap under the XIAO, and a long
    screw would have reached the XIAO's back (operator). Now at board
    (12.0, 4.0), nose z 29.4, under the USB-C plug room: the hole spans
    y 1.8-6.2, aft of the XIAO and its USB-C tab. Standoffs 81 mm apart;
    the camera ~14 mm from standoff 1. DRC 0 violations.
    The drawing now labels the other side's parts ("standoff, other side")
    so a part behind the board no longer reads as a hole through a module.
    Refs #22, jwilleke/js-rocket#99
    Cla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
    [PCB-carrier.kicad_pcb]
2026-09-11 feat(firmware): gps-check -- read the L76K directly, no Meshtastic (#6)
    PlatformIO project for XIAO-ESP32S3-cam. Reads the L76K on D6/D7 at
    9600 baud and prints fix type, satellites used and in view, best SNR,
    HDOP and checksum failures every 2 s, plus the time to first fix. It
    splits "module, antenna or wiring" from "stock Meshtastic not reading
    D6/D7" on a board that may be reflashed.
    The summary never prints a position; the raw NMEA toggle does, and says
    so, because this repo is public. The README now warns to unplug
    XIAO-ESP32S3-lora before any upload. Compiles; untested on hardware.
    Refs #6
    Claude-Session: https://claude.ai/code/s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
    [main.cpp]
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2026-09-12 feat(bench): cam XIAO bring-up -- sensors and IMU pass, buzzer measured (#7, #19)
    First run of bringup-cam on XIAO-ESP32S3-cam (MAC e0:72:a1:fa:41:30),
    on USB with no Sense board:
    - I2C: BMP388 at 0x77, chip ID 0x50; LSM6DSO32 at 0x6A, WHO_AM_I 0x6C
    - IMU: CTRL1_XL 0x74 (833 Hz, +/-32 g), 1.02 g on Z at rest, FIFO 81
    words in 100 ms
    - #19: both breakouts answer with CS unconnected -- their own pull-ups
    hold I2C
    - Buzzer: works, measured by microphone FFT rather than by ear -- 4 kHz
    strongest (~55 dB over noise), 3 kHz with a strong 9 kHz harmonic,
    1.2 kHz only as its harmonics. Everything the part makes sits at
    ~3.5-9 kHz, so a listener who cannot hear that band hears nothing
    The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
    [main.cpp]
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2026-09-12 feat(bench): join harness for #8, and soak-power keeps its reset history off the card
    - The operator's bench harness -- one battery JST into two XIAO pigtail
    JSTs -- photographed (GPS stripped) and written up on LiPo-500mAh.md.
    The battery's JST and the pigtails' JSTs are wired opposite ways; the
    harness crosses its wires to correct it and was metered at 3.95 V,
    red positive, at each plug. That is exactly the trap the carrier's
    owed "JST pin 1 against the battery's red lead" check is for.
    - soak-power appends every boot's reset reason, and the uptime the boot
    before reached, to a 32-entry ring in NVS and prints it at start-up, so
    a reset that kills the card still leaves a recor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
    [main.cpp]
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2026-09-15 feat(carrier): battery behind the board -- layout B2 in the generator
    Operator chose B2, 2026-09-15. gen_carrier.py: board 90.4 -> 115.7 mm
    (nose z 25.4-141.1), LSM6DSO32 aft to nose z 33.4-58.9, BMP388 forward to
    107.25-132.75, forward standoff to (16.5, 110.5) = nose z 135.9, 5.2 mm
    from the end and under no module. The battery lies on the low face between
    them, nose z 70.5-106.5, on a 1 mm pad. verify_clearances passes (72
    holes); kicad-cli DRC 0 violations, 10 unconnected (unrouted, as before).
    Layout JSON and diagram regenerated. README, BOM (carrier est 5.2 g, nose
    55.5 g), design, shopping list (~$40), LiPo, Antennas and the carrier pages
    updated. Owed: stability, span stiffness over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
    [PCB-carrier.kicad_pcb]
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2026-09-15 feat(carrier): 1.6 mm board, and a labelled fit mock to match
    OSH Park makes 4-layer boards in 1.6 mm only ("63mil (1.6mm) nominal").
    The 1.0 mm the generator and the docs carried was never checked against
    the fab; the operator caught it on the printed fit mock ("looks too thin").
    - gen_carrier.py: THICKNESS 1.0 -> 1.6. Checks pass, 72 holes clear;
    kicad-cli DRC 0 violations, 10 unconnected (the unrouted nets)
    - The low face stays at r 0.5, so the standoffs and the sled do not move;
    the tall side moves 0.6 mm toward 270. Cam stack top r 11.8, 2.3 mm to
    the camera pad floor (2.9 before); stack corners r 14.78 and 15.67, 5.2
    and 4.3 mm inside the door. About 4x as stiff over the 106.5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
    [PCB-carrier-fit-mock.stl, PCB-carrier.kicad_pcb]
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2026-09-15 feat(carrier): LSM6DSO32 slid 3.45 mm to clear the real XIAO rows; bare fit mock, paper template
    At Seeed's 15.24 mm XIAO spacing (#33) the LSM6DSO32's rows, 12.7 mm
    apart, cannot sit inside XIAO-ESP32S3-cam's. Operator, 2026-09-15: slide it.
    - gen_carrier.py: LSM_DX 3.45 -- its 9-pin row at x 21.81, outside the
    cam's x 19.62 row, the 5-pin row at x 9.11 inside. Holes 2.18 mm from the
    cam's. New check in verify_clearances(): every sensor joint clears every
    XIAO-pattern header's plastic by FILLET_R -- the check #33 was missing.
    Two silkscreen labels moved. All checks pass; kicad-cli DRC 0 violations,
    10 unconnected (the unrouted nets). Body ~0.36 mm past the board edge,
    corner r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
    [PCB-carrier-fit-mock.stl, PCB-carrier.kicad_pcb]
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
